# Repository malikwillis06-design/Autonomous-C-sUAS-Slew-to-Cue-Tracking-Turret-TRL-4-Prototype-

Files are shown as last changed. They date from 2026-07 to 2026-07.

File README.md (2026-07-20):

# Autonomous C-sUAS "Slew-to-Cue" Tracking Turret (TRL 4 Prototype)

An autonomous, low-cost ($245) C-sUAS Point-Defense tracking and ranging gimbal utilizing YOLO object detection, KLT optical flow, and closed-loop velocity-PD control.

This repository houses the source code, hardware architecture, and firmware for a low-latency Point-Defense target acquisition platform capable of processing real-time telemetry, sensor fusion, and high-accuracy servo actuation.

## 🎥 System Demonstration & HUD

*(Insert a high-quality GIF of your turret physically tracking a target side-by-side with your MATLAB/Python HUD tracking feed here)*

> **Live Demo Video:** https://youtube.com/shorts/hJJrJ_sbNVY?si=u6pjSPRpaa84ya5z

## 🎯 Core Engineering Features

* **Low-Latency Vision-to-Actuation Pipeline:** Employs a dual-routing tracking pipeline. The system runs deep learning object detection to acquire targets, then hands off tracking to a high-speed KLT (Kanade-Lucas-Tomasi) Optical Flow Tracker.
* **Low-Overhead Custom Binary Protocol:** Replaced slow ASCII string serial parsing on the microcontroller with a custom 5-byte raw binary telemetry protocol over USB/UART, reducing serial processing overhead on the Arduino R4 from ~3ms to <20 microseconds.
* **Velocity-PD Control Loop:** Implements a localized, dynamically tuned Velocity-Proportional-Derivative (PD) feedback loop to eliminate physical servo overshoot and mechanical backlash, stabilizing the tracking frame to within +/- 3 pixels of target centers.
* **Resolution-Independent Scaling:** Features a spatial transformation matrix mapping coordinate errors to a normalized reference grid (640 x 360) to ensure uniform controller gains regardless of sensor upgrades (including 4K feeds).
* **Sensor Fusion & Telemetry:** Integrates a TF-Luna LiDAR sensor over TTL serial, writing custom parsing routines to fuse absolute ranging data with real-time visual coordinate estimation.

## 🛠️ System Architecture

```text
                       +-----------------------------+
                       |   Targeting / Command PC    |
                       | (MATLAB / Python Engine)    |
                       +--------------+--------------+
                                      |
                                      | 5-Byte Raw Binary Packet
                                      | (115200 Baud, USB-Serial)
                                      v
                       +--------------+--------------+
                       |      Arduino R4 Minima      |
                       +--------------+--------------+
                                      |
                        I2C Bus       | (50 Hz PWM Signals)
                        (0x40)        v
+------------------------+     +------+------+     +-------------------------+
|   PCA9685 PWM Driver   +---->|  Pan Servo  |     |      TF-Luna LiDAR      |
|  (Ext. 5V Power Rails) |     +-------------+     | (Direct Target Ranging) |
+------------------------+     +-------------+     +------------+------------+
                               |  Tilt Servo |                  |
                               +-------------+                  | TTL Serial
                                                                v
                                                       (To Command PC/Arduino)
   
Create and activate a virtual environment:Bash   python -m venv venv
   .\venv\Scripts\activate
   
Install the required computer vision and robotics packages:Bash   pip install pyserial opencv-python ultralytics numpy
   
Firmware (Arduino R4 Setup)Connect your Arduino Uno R4 Minima to your PC.Open firmware/turret_actuator_binary.ino in the Arduino IDE.Install the Adafruit PWM Servo Driver Library via the Library Manager.Upload the code to your Arduino.Check Device Manager to verify your Arduino's assigned COM port.💻 Running the SystemUpdate the COM_PORT and CAMERA_INDEX variables in src/turret_master.py to match your PC's environment.Run the master tracking script:Bash   python src/turret_master.py
   
Focus your camera on a target. Press q in the window to stop tracking and park the servos safely at their neutral coordinates (375, 375).📁 Repository StructurePlaintextautonomous-target-tracking-turret/
│
├── firmware/
│   └── turret_actuator_binary.ino      # Arduino R4 firmware (reads binary payloads)
│
├── src/
│   ├── turret_master.py         # Production Python tracking controller (YOLO)
│   ├── train_model.py                  # AI training execution script
│   └── find_camera.py                  # Windows camera index scanner utility
│
├── docs/
│   ├── schematics_wiring.png           # Fritzing/CAD wiring diagram
│   └── system_block_diagram.png        # System-of-systems flow diagram
│
├── README.md                           # Main developer documentation
└── LICENSE                             # Proprietary License Agreement
🔒 Intellectual Property & Proprietary LicensingThis repository and its contents are the proprietary intellectual property of Willis Aero Tech LLC. All rights are reserved. This source code and structural design are published strictly for educational, portfolio evaluation, and academic demonstration purposes. Commercial or military reproduction, modification, distribution, or deployment of this software or hardware design is strictly prohibited without explicit, written licensing authorization from Willis Aero Tech LLC

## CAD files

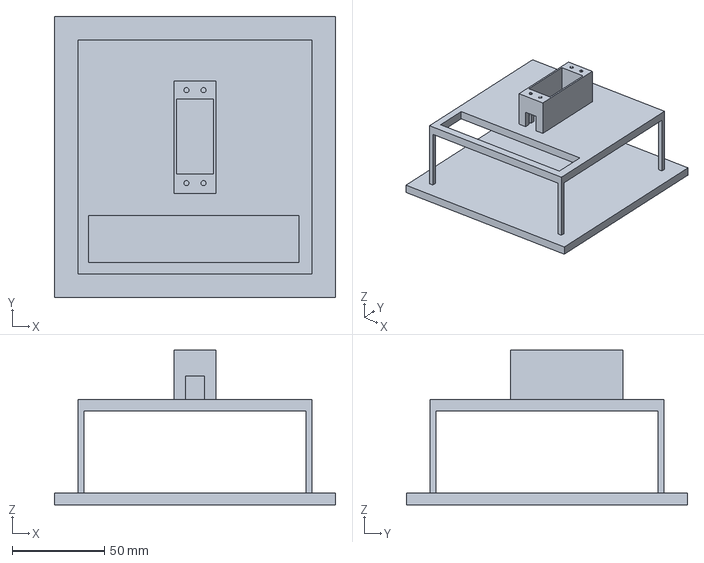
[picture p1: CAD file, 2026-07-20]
pan1.3MF
152.4 x 152.4 x 83.8 mm

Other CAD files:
tilt2holder4.gcode.3mf

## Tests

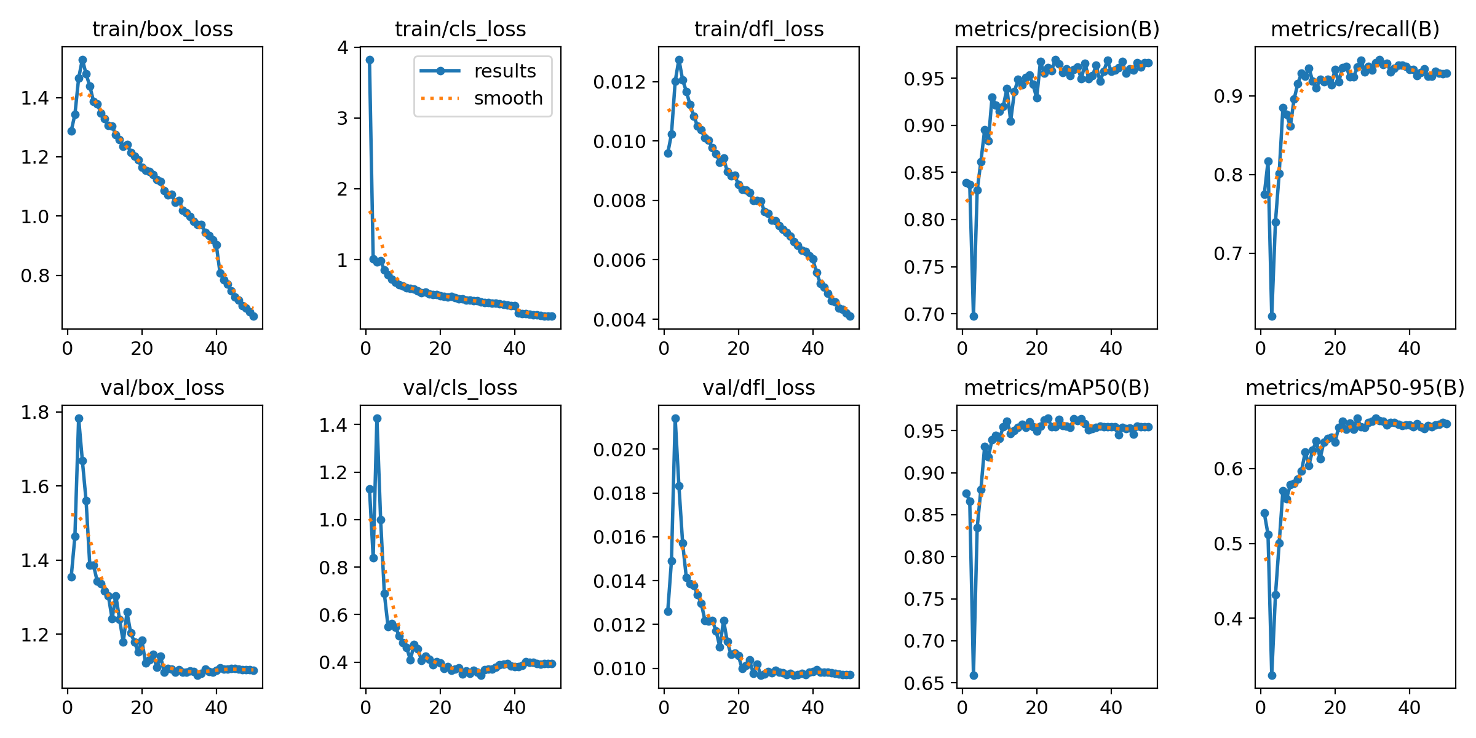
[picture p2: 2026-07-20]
results.png

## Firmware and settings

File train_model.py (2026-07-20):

from ultralytics import YOLO

def train_turret_brain():
    # 1. Start with the pretrained YOLO26 Nano (the base "eyes")
    # This model is lightweight and perfect for real-time turret tracking
    model = YOLO('yolo26n.pt') 
    
    # 2. Train on your custom dataset
    # Make sure 'data.yaml' is in the same folder as this script
    # This will use your NVIDIA GPU automatically via CUDA
    model.train(
        data='data.yaml', 
        epochs=50,          # Adjust this based on how long you want to train
        imgsz=640,          # Standard input size for high accuracy
        device=0,           # 0 indicates your primary NVIDIA GPU
        batch=16,           # Increase this if you have high VRAM, decrease if you get OOM errors
        name='turret_v1'    # This creates a folder in 'runs/detect/' with your results
    )

    print("Training Complete. Your custom weights are in runs/detect/turret_v1/weights/best.pt")

if __name__ == '__main__':
    train_turret_brain()

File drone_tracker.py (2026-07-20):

import time

import cv2
import serial
from ultralytics import YOLO


# ============================================================
# USER SETTINGS
# ============================================================

COM_PORT = "COM4"
BAUD_RATE = 115200

CAMERA_INDEX = 1
MODEL_FILE = "drone_brain_v1.pt"

CONFIDENCE_THRESHOLD = 0.50


# ============================================================
# CAMERA / OPTICS SETTINGS
# ============================================================

# Measure these for your actual camera/lens combo (check the
# datasheet, or measure empirically by pointing at two known
# reference points and computing the angle between them).
# Getting this right is what makes the gain physically meaningful
# instead of an arbitrary tuned number.
HORIZONTAL_FOV_DEG = 67.0
VERTICAL_FOV_DEG = 53.7


# ============================================================
# SERVO SETTINGS
# ============================================================

PAN_NEUTRAL = 375
TILT_NEUTRAL = 375

# Full configured range for the 270-degree servos.
MIN_PWM = 150
MAX_PWM = 600
SERVO_TRAVEL_DEG = 270.0
PWM_PER_DEGREE = (MAX_PWM - MIN_PWM) / SERVO_TRAVEL_DEG

# Corrected directions based on the previous test.
PAN_DIRECTION = -1
TILT_DIRECTION = -1


# ============================================================
# TRACKING SETTINGS
# ============================================================

# Ignore small errors to prevent slow endpoint drift.
# Kept tight since error is now measured in PWM-equivalent degrees,
# not raw pixels, so this is no longer resolution-dependent.
DEADZONE_PWM = 3.0

# Gains now operate on "PWM degrees of error" rather than raw pixels,
# and the derivative term is normalized by real elapsed time (dt),
# so these should need less re-tuning if camera or frame rate changes.
# START HERE: KD=0, raise KP until you see slight oscillation around
# the target, then back off ~30-40%. Only then start raising KD from
# 0 in small increments (e.g. 0.005 at a time).
KP = 0.15
KD = 0.0

# Derivative is low-pass filtered (see DERIVATIVE_FILTER_ALPHA below)
# before KD is applied, since raw frame-to-frame derivative divided
# by a small dt amplifies ordinary detection jitter into large kicks.
DERIVATIVE_FILTER_ALPHA = 0.3

# Step limits scale with how far off-target we are: small steps near
# lock for precision, larger steps for big corrections so the turret
# doesn't lag behind fast motion. Lowered from the first pass since
# 18 PWM/frame was too aggressive at this loop's effective frame rate.
MAX_STEP_SMALL = 2.0
MAX_STEP_LARGE = 8.0
LARGE_ERROR_THRESHOLD_PWM = 25.0

# Exponential smoothing factor for the detected target center.
# Higher = more responsive but jittery; lower = smoother but laggier.
SMOOTHING_ALPHA = 0.6


def clamp(value, minimum, maximum):
    return max(minimum, min(maximum, value))


def send_servo_positions(serial_port, pan_value, tilt_value):
    """
    Send:
    [header, pan high, pan low, tilt high, tilt low]
    """

    pan_value = int(clamp(pan_value, MIN_PWM, MAX_PWM))
    tilt_value = int(clamp(tilt_value, MIN_PWM, MAX_PWM))

    packet = bytes(
        [
            255,
            (pan_value >> 8) & 0xFF,
            pan_value & 0xFF,
            (tilt_value >> 8) & 0xFF,
            tilt_value & 0xFF,
        ]
    )

    serial_port.write(packet)


def pixel_error_to_pwm_degrees(error_px, frame_dimension_px, fov_deg):
    """
    Convert a pixel error into an equivalent PWM-tick error, using
    the camera's field of view and the servo's PWM-per-degree.
    This makes the error physically meaningful instead of an
    arbitrary pixel count, so gains transfer across resolutions,
    cameras, and lenses.
    """

    degrees_per_px = fov_deg / frame_dimension_px

    return error_px * degrees_per_px * PWM_PER_DEGREE


def calculate_servo_step(
    error_pwm,
    previous_error_pwm,
    previous_filtered_derivative,
    dt,
    direction,
):
    """
    Calculate one PD controller movement step.

    error_pwm: current error, already converted to PWM-equivalent
               degrees via pixel_error_to_pwm_degrees().
    dt:        seconds elapsed since the previous frame's error was
               computed. Normalizes the derivative term so gains
               don't drift with variable inference time.

    The raw derivative (error delta / dt) is extremely sensitive to
    ordinary detection jitter -- a few pixels of noise divided by a
    small dt produces a large spike. It's passed through a low-pass
    filter (DERIVATIVE_FILTER_ALPHA) before KD is applied, so only
    sustained motion trends drive the derivative term, not frame-to-
    frame noise.
    """

    if abs(error_pwm) <= DEADZONE_PWM:
        return 0.0, error_pwm, previous_filtered_derivative

    dt = max(dt, 1e-3)  # guard against div-by-zero / huge spikes

    raw_derivative = (error_pwm - previous_error_pwm) / dt

    filtered_derivative = (
        DERIVATIVE_FILTER_ALPHA * raw_derivative
        + (1 - DERIVATIVE_FILTER_ALPHA) * previous_filtered_derivative
    )

    step = direction * (
        (error_pwm * KP) +
        (filtered_derivative * KD)
    )

    step_limit = (
        MAX_STEP_LARGE
        if abs(error_pwm) > LARGE_ERROR_THRESHOLD_PWM
        else MAX_STEP_SMALL
    )

    step = clamp(step, -step_limit, step_limit)

    return step, error_pwm, filtered_derivative


print("System booting...")

arduino = None
camera = None
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
